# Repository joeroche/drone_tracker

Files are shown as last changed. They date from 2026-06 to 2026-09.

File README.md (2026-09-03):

# Drone Tracker

An ESP32-CAM pan/tilt prototype that streams JPEG frames over its own Wi-Fi
network, runs open-vocabulary detection on a Mac, and moves the camera to keep a
text-prompted target near the image center.

**[Watch the hardware prototype track a target](https://youtu.be/l-cdVXwM77g).**
The video shows this single-board architecture on the original mount.

## Main limitation

I deliberately ran inference on my Mac instead of renting a GPU server to test
the practical limits of local inference (and save money). Grounding DINO could not run at the
camera frame rate, so it periodically created or corrected the target box while
pyramidal Lucas-Kanade optical flow propagated that box between model passes.
This kept the loop responsive, but KLT can accumulate drift until the next
detection. Faster GPU inference would permit more frequent corrections; this
repository does not claim a measured latency or accuracy benchmark as they would be too noisy anyway.

## System at a glance

The AI Thinker ESP32-CAM creates the `DroneTracker` access point, captures QVGA
JPEG frames, and sends length-prefixed images to a Mac over one TCP connection.
A receiver thread keeps only the newest complete frame, preventing detector
latency from building a stale-image backlog.

Grounding DINO Tiny periodically localizes the prompted target. Between those
refreshes, Shi-Tomasi features inside the target box are propagated with
pyramidal KLT optical flow, and the median surviving displacement translates
the box. The system starts in calibration mode where you center the drone in its view while it makes micro-adjustments. Once calibrations are made, they are persistent until reset through serial. The Mac converts box-center error into bounded pan/tilt angles and
returns a four-byte command over the same socket.

The detector is pinned to
[`IDEA-Research/grounding-dino-tiny`](https://huggingface.co/IDEA-Research/grounding-dino-tiny),
uses a 480-pixel short edge with a 640-pixel maximum edge, and selects Apple
Metal (`mps`) automatically when available. PyTorch falls back to CPU for an
unsupported MPS operation. The model is downloaded before joining the isolated
ESP32 access point and then loaded from the local cache.

Grounding DINO refreshes every 10 processed frames or immediately after KLT
loses the target. KLT uses a 7 x 7 window and two pyramid levels; fewer than three
surviving points kills the track and forces another detection.

## Alignment and transport

The Mac converts the tracked box center into normalized image error:

```text
ex = (bbox_center_x - frame_center_x) / (frame_width / 2)
ey = (bbox_center_y - frame_center_y) / (frame_height / 2)

pan  = clamp(90 + 90*EMA(ex) + pan_offset,  0, 180)
tilt = clamp(90 + 90*EMA(ey) + tilt_offset, 0, 180)
```

## Run it

```sh
python3 -m venv .venv
.venv/bin/python -m pip install -e ".[dev]"
.venv/bin/drone-tracker-download-model

# After flashing the firmware, join Wi-Fi "DroneTracker" with password "dronetrack"
.venv/bin/drone-tracker --offline --device mps --prompt "a small drone"
```

Use `--no-servos` for vision-only testing. See [BUILD.md](BUILD.md) for wiring,
firmware compilation, model caching, and the ordered bring-up procedure.

## Explore the implementation

| Area | Start here |
| --- | --- |
| Runtime loop | [`drone_tracker/app.py`](drone_tracker/app.py) |
| Grounding DINO and MPS | [`drone_tracker/detector.py`](drone_tracker/detector.py) |
| Shi-Tomasi and KLT | [`drone_tracker/tracking.py`](drone_tracker/tracking.py) |
| TCP framing | [`drone_tracker/transport.py`](drone_tracker/transport.py) |
| Alignment control | [`drone_tracker/control.py`](drone_tracker/control.py) |
| ESP32-CAM firmware | [`firmware/esp32_cam_tracker`](firmware/esp32_cam_tracker) |
| Protocol and timing | [ARCHITECTURE.md](ARCHITECTURE.md) |
| Mechanical files | [`cad`](cad) - STEP assembly and four printable 3MF parts |

## Revisions

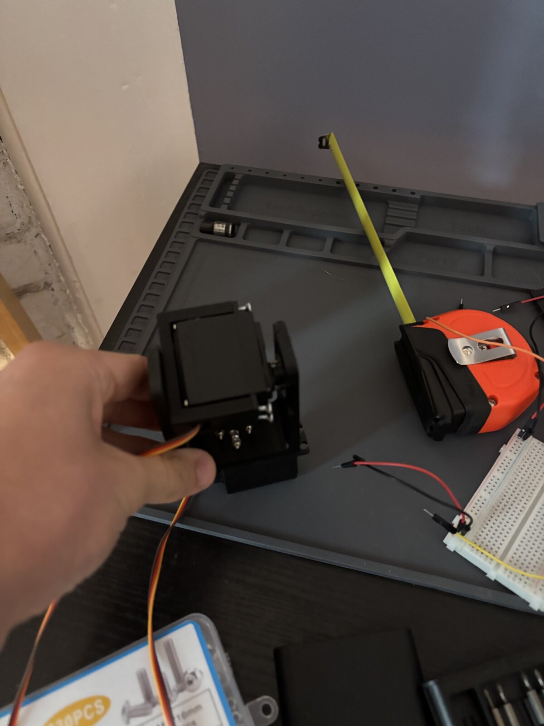
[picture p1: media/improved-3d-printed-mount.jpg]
Improved 3D printed mount.


*Improved 3D printed mount that was made after the demo.*

This project could be vastly improved with GPU inference and a fine-tuned model for drones, but I lacked the resources at the time of production. An updated version with a dual-esp32 mechanism and more advanced tracking pipeline has been in the works, but paused due to higher priority work in university. A rough version of its codebase can be seen in the archive/dual-esp32 branch.

## License

MIT. See [LICENSE](LICENSE).

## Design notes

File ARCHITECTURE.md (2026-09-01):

# Architecture

## Physical topology

The AI Thinker ESP32-CAM is both the camera endpoint and actuator controller.
It creates a WPA2 access point named `DroneTracker` on channel 6 with address
`192.168.4.1`. The Mac joins that network and opens one TCP connection to port
5005. No router, second ESP32, browser service, or remote inference server is
part of this branch.

The same socket is bidirectional:

- ESP32-CAM to Mac: framed JPEG images.
- Mac to ESP32-CAM: four-byte servo commands.

## Wire protocols

Each JPEG begins with a six-byte little-endian header:

```text
offset  size  value
0       2     0xFF 0xAA
2       4     JPEG payload length, uint32 little-endian
6       N     JPEG bytes
```

The Mac rejects zero-length frames and frames larger than 200,000 bytes. Its
incremental parser searches for the marker after corruption and retains a
trailing `0xFF` when the marker is divided across two TCP reads. A receiver
thread publishes complete JPEGs into a queue of length one, evicting the older
frame whenever the application is still processing.

Each servo command is four bytes:

```text
offset  size  value
0       2     0xBB 0xCC
2       1     pan angle, uint8, clamped to 0-180
3       1     tilt angle, uint8, clamped to 0-180
```

The firmware consumes the byte stream with a four-state marker parser so a
partial command is retained across loop iterations.

## Frame lifecycle

1. The OV2640 captures QVGA JPEG at a target rate of 10 fps. With PSRAM, the
   firmware uses two frame buffers and `CAMERA_GRAB_LATEST`; without PSRAM, it
   falls back to one DRAM buffer and `CAMERA_GRAB_WHEN_EMPTY`.
2. The Mac receiver decodes the newest complete JPEG with OpenCV and rotates it
   180 degrees for the physical camera orientation.
3. Every tenth processed frame, or whenever tracking is lost, Grounding DINO
   runs synchronously on that frame and returns the highest-confidence box for
   the configured text prompt.
4. The new box becomes a mask for `cv2.goodFeaturesToTrack`: at most 20 corners,
   quality level 0.20, minimum spacing 7 pixels, and block size 7.
5. On intervening frames, `cv2.calcOpticalFlowPyrLK` propagates the points with
   a 7 x 7 search window, two pyramid levels, and a 10-iteration/0.03-epsilon
   termination criterion.
6. The median surviving point displacement translates the entire bounding box.
   Fewer than three surviving points clears the track and requests immediate
   Grounding DINO inference.
7. An EMA with `alpha=0.40` filters horizontal and vertical box-center error.
   Outside a 10-pixel dead zone, normalized error maps to servo angles and the
   four-byte command returns over the camera socket.

Inference blocks the main processing loop, but it does not block the receiver
thread. Frames arriving during inference replace one another in the one-slot
queue, so processing resumes from the newest received image instead of working
through an obsolete backlog.

## macOS inference path

The branch pins `IDEA-Research/grounding-dino-tiny` to model revision
`a2bb814dd30d776dcf7e30523b00659f4f141c71`. Hugging Face Transformers provides
the processor and `AutoModelForZeroShotObjectDetection`; PyTorch runs the model
under `torch.inference_mode()`.

Device selection is `mps` when `torch.backends.mps.is_available()` and `cpu`
otherwise. `PYTORCH_ENABLE_MPS_FALLBACK=1` allows an unsupported MPS operation
to execute on CPU. Input resizing is bounded to a 480-pixel short edge and a
640-pixel long edge rather than the processor's larger general-purpose default.
The first model download occurs while the Mac still has Internet access; the
runtime uses `--offline` after the Mac joins the ESP32 access point.

## Limits

- The video is evidence of the physical prototype, not a controlled latency or
  accuracy benchmark.
- KLT assumes short-term appearance consistency and mostly translational box
  motion. Occlusion, scale change, blur, or weak corner texture can cause drift.
- Servo mapping is proportional image alignment, not a dynamic plant model.
- The ESP32 access point isolates the Mac from its normal Wi-Fi network while
  connected unless the Mac has another network interface.

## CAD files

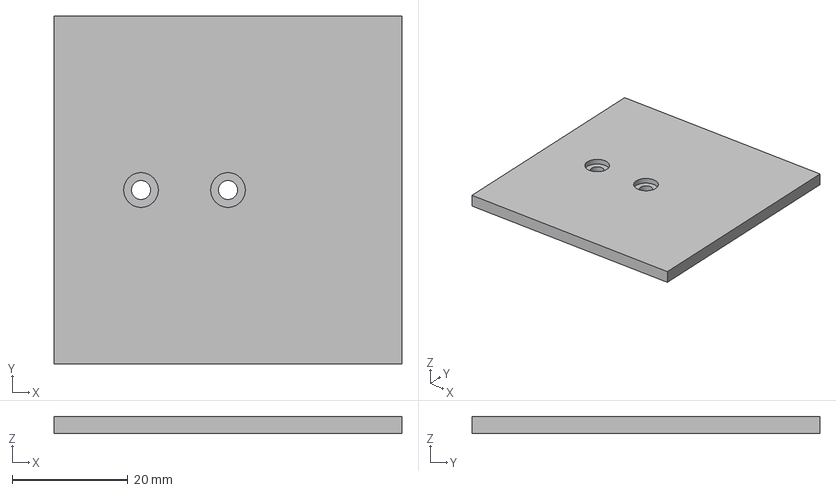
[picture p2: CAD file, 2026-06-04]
cad/tracker_p4.3mf
60.0 x 60.0 x 3.00 mm

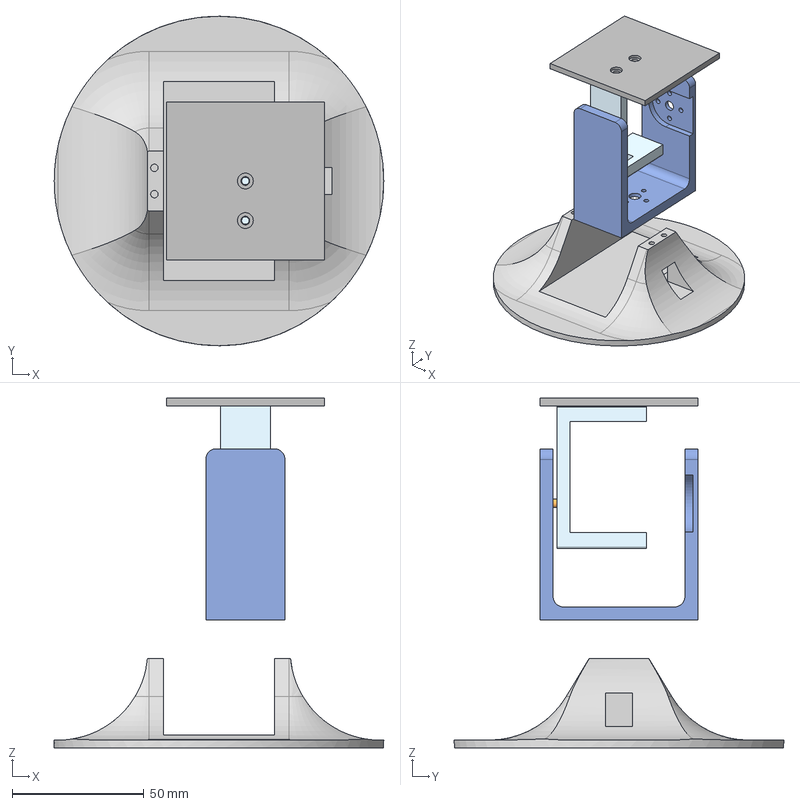
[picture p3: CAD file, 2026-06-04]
cad/Tracker.step
125.0 x 125.0 x 132.8 mm
Mount
Bot
Top
Stand
Joint

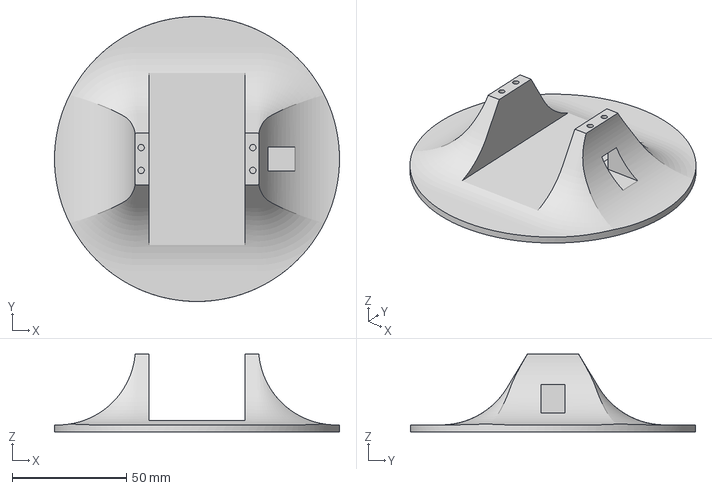
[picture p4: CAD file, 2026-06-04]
cad/tracker_p1.3mf
125.0 x 125.0 x 34.0 mm

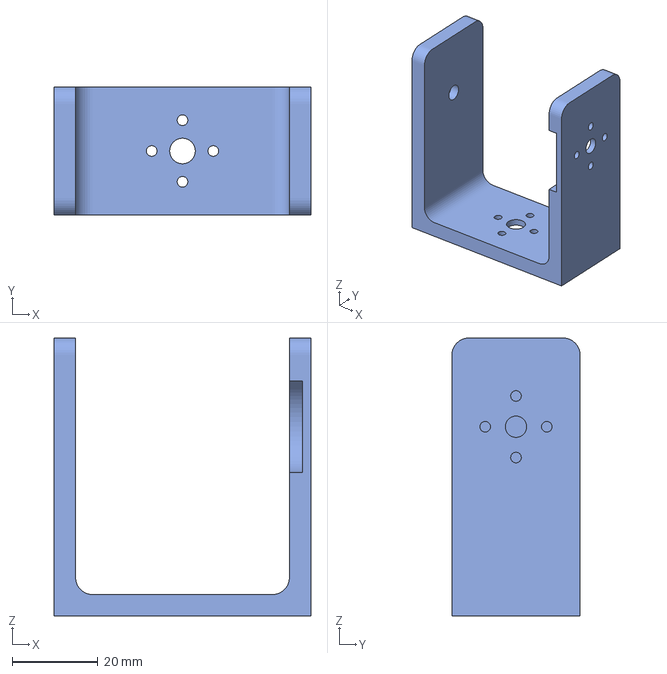
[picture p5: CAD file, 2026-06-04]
cad/tracker_p2.3mf
60.0 x 30.0 x 65.0 mm

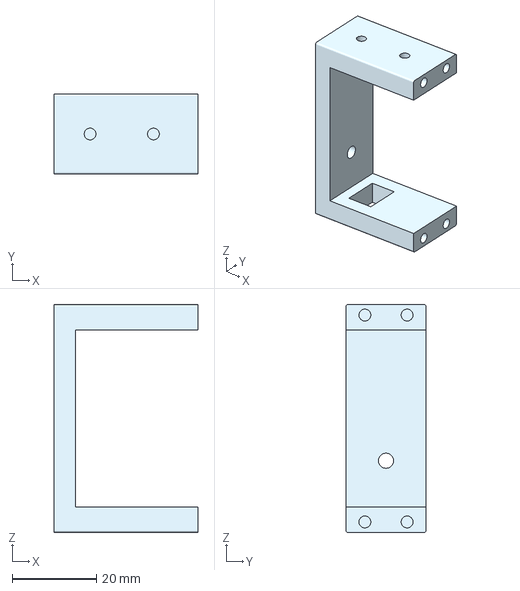
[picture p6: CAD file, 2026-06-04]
cad/tracker_p3.3mf
34.0 x 19.0 x 54.0 mm

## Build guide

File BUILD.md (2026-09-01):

# Build and Run

## Hardware

- AI Thinker ESP32-CAM with OV2640 camera
- USB-to-serial programmer for flashing
- Two hobby servos on GPIO 14 and GPIO 15
- External regulated 5 V servo supply
- Common ground between the servo supply and ESP32-CAM

Do not power the servos from the ESP32-CAM regulator. Remove the servo horns for
the first command test if the mount can collide with its physical stops.

## Firmware toolchain

Install Arduino CLI, the ESP32 platform, and ESP32Servo:

```sh
brew install arduino-cli
arduino-cli core update-index
arduino-cli core install esp32:esp32
arduino-cli lib install ESP32Servo
tools/compile_firmware.sh
```

To upload, first list attached boards, then pass the selected serial device to
the upload helper:

```sh
arduino-cli board list
tools/upload_firmware.sh /dev/cu.usbserial-DEVICE
```

GPIO 0 must be connected to ground while flashing and disconnected before
normal boot. The firmware starts the `DroneTracker` access point with password
`dronetrack`, listens at `192.168.4.1:5005`, streams QVGA JPEG at 10 fps, and
accepts servo commands over the same socket.

## macOS environment

Create the environment while the Mac is connected to normal Internet:

```sh
python3 -m venv .venv
.venv/bin/python -m pip install --upgrade pip
.venv/bin/python -m pip install -e ".[dev]"
.venv/bin/drone-tracker-download-model
```

The download command caches the pinned Grounding DINO Tiny processor and model.
This step matters because joining the ESP32 access point normally disconnects
the Mac from Internet Wi-Fi.

Verify Apple Metal acceleration:

```sh
.venv/bin/python -c 'import torch; print(torch.backends.mps.is_available())'
```

On an Apple-silicon Mac with a supported PyTorch build, the command should print
`True`. The tracker still supports `--device cpu`.

## Ordered bring-up

1. Flash the ESP32-CAM, disconnect GPIO 0 from ground, and reset the board.
2. Confirm serial output reports `192.168.4.1:5005`.
3. Leave both servo horns detached and connect the external 5 V servo supply.
4. Join Wi-Fi `DroneTracker` using password `dronetrack`.
5. Start vision without actuator output:

   ```sh
   .venv/bin/drone-tracker --offline --device mps --no-servos --prompt "a small drone"
   ```

6. Confirm detections refresh and KLT points follow the target. Press `q` to
   exit.
7. Center the mount mechanically, attach the horns, and start the complete loop:

   ```sh
   .venv/bin/drone-tracker --offline --device mps --prompt "a small drone"
   ```

8. If the optical and mechanical centers differ, add measured offsets:

   ```sh
   .venv/bin/drone-tracker --offline --device mps --pan-offset 3 --tilt-offset -2
   ```

Positive offsets add degrees to the corresponding command. Stop immediately if
the mechanism binds or the ESP32 resets under servo load.

## Software verification

```sh
.venv/bin/python -m pytest -q
.venv/bin/python -m compileall -q drone_tracker tests
tools/compile_firmware.sh
```

The Python tests cover stream resynchronization, split markers, frame-size
rejection, command encoding, alignment math, KLT box translation, and device
selection. They do not substitute for the physical bring-up sequence.

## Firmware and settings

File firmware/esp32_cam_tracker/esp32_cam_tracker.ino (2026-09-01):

#include <Arduino.h>
#include <ESP32Servo.h>
#include <WiFi.h>
#include "esp_camera.h"
#include "camera_pins.h"

static const char *AP_SSID = "DroneTracker";
static const char *AP_PASSWORD = "dronetrack";
static const uint8_t AP_CHANNEL = 6;
static const uint16_t TCP_PORT = 5005;
static const uint8_t TARGET_FPS = 10;

static const int PAN_SERVO_PIN = 14;
static const int TILT_SERVO_PIN = 15;
static const int SERVO_MIN_US = 500;
static const int SERVO_MAX_US = 2500;

static WiFiServer server(TCP_PORT);
static WiFiClient client;
static Servo panServo;
static Servo tiltServo;
static uint32_t lastFrameMs = 0;
static uint8_t commandState = 0;
static uint8_t pendingPan = 90;

static bool writeAll(WiFiClient &out, const uint8_t *data, size_t length) {
  size_t sent = 0;
  while (sent < length && out.connected()) {
    const size_t count = out.write(data + sent, length - sent);
    if (count == 0) {
      delay(1);
      continue;
    }
    sent += count;
  }
  return sent == length;
}

static bool sendFrame(WiFiClient &out) {
  camera_fb_t *frame = esp_camera_fb_get();
  if (frame == nullptr) {
    Serial.println("camera capture failed");
    return false;
  }
  const uint32_t size = static_cast<uint32_t>(frame->len);
  const uint8_t header[6] = {
    0xFF,
    0xAA,
    static_cast<uint8_t>(size & 0xFF),
    static_cast<uint8_t>((size >> 8) & 0xFF),
    static_cast<uint8_t>((size >> 16) & 0xFF),
    static_cast<uint8_t>((size >> 24) & 0xFF),
  };
  const bool ok = writeAll(out, header, sizeof(header))
    && writeAll(out, frame->buf, frame->len);
  esp_camera_fb_return(frame);
  return ok;
}

static void consumeServoCommands(WiFiClient &input) {
  while (input.available()) {
    const uint8_t value = static_cast<uint8_t>(input.read());
    switch (commandState) {
      case 0:
        commandState = value == 0xBB ? 1 : 0;
        break;
      case 1:
        commandState = value == 0xCC ? 2 : (value == 0xBB ? 1 : 0);
        break;
      case 2:
        pendingPan = value;
        commandState = 3;
        break;
      case 3:
        panServo.write(constrain(static_cast<int>(pendingPan), 0, 180));
        tiltServo.write(constrain(static_cast<int>(value), 0, 180));
        commandState = 0;
        break;
    }
  }
}

static bool initializeCamera() {
  camera_config_t config = {};
  config.ledc_channel = LEDC_CHANNEL_0;
  config.ledc_timer = LEDC_TIMER_0;
  config.pin_d0 = Y2_GPIO_NUM;
  config.pin_d1 = Y3_GPIO_NUM;
  config.pin_d2 = Y4_GPIO_NUM;
  config.pin_d3 = Y5_GPIO_NUM;
  config.pin_d4 = Y6_GPIO_NUM;
  config.pin_d5 = Y7_GPIO_NUM;
  config.pin_d6 = Y8_GPIO_NUM;
  config.pin_d7 = Y9_GPIO_NUM;
  config.pin_xclk = XCLK_GPIO_NUM;
  config.pin_pclk = PCLK_GPIO_NUM;
  config.pin_vsync = VSYNC_GPIO_NUM;
  config.pin_href = HREF_GPIO_NUM;
  config.pin_sccb_sda = SIOD_GPIO_NUM;
  config.pin_sccb_scl = SIOC_GPIO_NUM;
  config.pin_pwdn = PWDN_GPIO_NUM;
  config.pin_reset = RESET_GPIO_NUM;
  config.xclk_freq_hz = 20000000;
  config.pixel_format = PIXFORMAT_JPEG;
  config.frame_size = FRAMESIZE_QVGA;
  config.jpeg_quality = 12;
  config.fb_location = psramFound() ? CAMERA_FB_IN_PSRAM : CAMERA_FB_IN_DRAM;
  config.fb_count = psramFound() ? 2 : 1;
  config.grab_mode = psramFound() ? CAMERA_GRAB_LATEST : CAMERA_GRAB_WHEN_EMPTY;
  return esp_camera_init(&config) == ESP_OK;
}

void setup() {
  Serial.begin(115200);
  delay(200);
  if (!initializeCamera()) {
    Serial.println("camera initialization failed");
    return;
  }

  panServo.setPeriodHertz(50);
  tiltServo.setPeriodHertz(50);
  panServo.attach(PAN_SERVO_PIN, SERVO_MIN_US, SERVO_MAX_US);
  tiltServo.attach(TILT_SERVO_PIN, SERVO_MIN_US, SERVO_MAX_US);
  panServo.write(90);
  tiltServo.write(90);

  WiFi.mode(WIFI_AP);
  WiFi.setSleep(false);
  if (!WiFi.softAP(AP_SSID, AP_PASSWORD, AP_CHANNEL, false, 1)) {
    Serial.println("access point startup failed");
    return;
  }
  server.begin();
  server.setNoDelay(true);
  Serial.printf("join %s and connect to %s:%u\n", AP_SSID, WiFi.softAPIP().toString().c_str(), TCP_PORT);
}

void loop() {
  if (!client || !client.connected()) {
    if (client) {
      client.stop();
    }
    client = server.available();
    if (!client) {
      delay(2);
      return;
    }
    client.setNoDelay(true);
    commandState = 0;
    Serial.println("Mac connected");
  }

  consumeServoCommands(client);
  const uint32_t nowMs = millis();
  if (nowMs - lastFrameMs >= 1000U / TARGET_FPS) {
    lastFrameMs = nowMs;
    if (!sendFrame(client)) {
      client.stop();
    }
  }
  consumeServoCommands(client);
}

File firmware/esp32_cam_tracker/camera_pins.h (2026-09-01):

#pragma once

#define PWDN_GPIO_NUM 32
#define RESET_GPIO_NUM -1
#define XCLK_GPIO_NUM 0
#define SIOD_GPIO_NUM 26
#define SIOC_GPIO_NUM 27
#define Y9_GPIO_NUM 35
#define Y8_GPIO_NUM 34
#define Y7_GPIO_NUM 39
#define Y6_GPIO_NUM 36
#define Y5_GPIO_NUM 21
#define Y4_GPIO_NUM 19
#define Y3_GPIO_NUM 18
#define Y2_GPIO_NUM 5
#define VSYNC_GPIO_NUM 25
#define HREF_GPIO_NUM 23
#define PCLK_GPIO_NUM 22

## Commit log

2026-06-04 chore(repo): initialize project structure
    [Tracker.step, calibration.example.yaml, tracker_p1.3mf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]
2026-06-04 feat(camera): add ai thinker streaming firmware
2026-08-19 feat(tracking): add multi-mode control workflow
    [calibration.example.yaml]
2026-08-26 docs(portfolio): add visual and prototype evidence
2026-09-01 docs: distinguish filmed prototype from later revision
2026-09-01 feat: implement single-ESP32-CAM Grounding DINO KLT tracker
    Reconstruct demonstrated hardware prototype: ESP32-CAM creates Wi-Fi AP,
    Mac joins AP and receives JPEG frames over TCP. Grounding DINO Tiny
    detects targets via PyTorch + Apple MPS backend. Pyramidal Lucas-Kanade
    optical flow propagates bounding boxes between detector refreshes for
    responsive control loop. Servo commands return over same TCP socket.
    - Implement drone_tracker Python package with detector, tracking, control,
    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
    [calibration.example.yaml]
2026-09-01 fix(tracking): harden KLT motion and servo control
2026-09-02 chore(docs): Improve mount description
2026-09-02 chore(docs): Update README with calibration mode details
